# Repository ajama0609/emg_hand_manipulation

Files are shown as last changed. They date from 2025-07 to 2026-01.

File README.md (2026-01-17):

# EMG Hand Gesture Classification

## Introduction

Surface electromyography (sEMG) is a non-invasive technique for measuring muscle electrical activity and is widely used in human–machine interfaces, prosthetics, and rehabilitation systems. Reliable sEMG systems require low-noise analog front-ends, high common-mode rejection, stable power delivery, and careful PCB layout to preserve signal integrity, particularly given the low-amplitude (µV–mV) nature of EMG signals.

This project details the design, fabrication, and validation of a custom surface electromyography (sEMG) acquisition board intended to capture high-fidelity muscle signals for both real-time and offline analysis. Bypassing commercial development kits, a fully custom printed circuit board (PCB) was developed to directly address the practical engineering challenges inherent in analog signal conditioning, proper grounding techniques, filtering, and the integration of mixed-signal systems ---

# Hardware Development and Testing
A custom sEMG acquisition hardware board has been designed and fabricated to enable lightweight, low-latency, and high-fidelity signal capture for real-time applications.

Custom sEMG Acquisition Board 
 
 

### Key Components and BOM Highlights:

- **Instrumentation Amplifiers:** Texas Instruments INA333 (3 units) for high CMRR and low noise EMG signal amplification  
- **Microcontroller:** STM32F103C8T6 (ARM Cortex-M3) for signal processing and data acquisition  
- **Power Management:** Microchip MIC5504-3.3 LDO regulator for stable 3.3V supply  
- **ESD Protection:** STMicroelectronics USBLC6-2SC6 for USB interface protection  
- **Passive Components:** High-quality capacitors (e.g., TDK X5R, KEMET), resistors (Susumu, Yageo), and ferrite bead (Murata) for noise filtering and stable operation  
- **Connectors:** USB-C receptacle, 3.5mm audio jacks for signal output and power input  
- **Oscillator:** EPSON 16MHz crystal for clock generation

---

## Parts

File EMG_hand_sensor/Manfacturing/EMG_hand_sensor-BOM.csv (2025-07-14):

Designator | Quantity | Manufacturer | Manufacturer Part Number | Description | Package | Value | Type | Global Sourcing
C1 | 1 | TDK | C2012X5R1E106M125AB | 10uF Cap | 0805 | 10uF | Capacitor
C2,C3,C4,C5,C6,C16,C17,C18,C19,C20,C21 | 11 | Vishay / Vitramon | GA0805Y104KBBBT31G | 100nF Cap | 0805 | 100nF | Capacitor
C7 | 1 | KEMET | C0805X103JCRAC3316 | 10nF Cap | 0805 | 10nF | Capacitor
C8,C9,C11,C12 | 4 | KEMET | C0805X105J5RACAUTO | 1uF Cap | 0805 | 1uF | Capacitor
C13 | 1 | Vishay / Vitramon | GA0805Y104KBBBT31G | 100nF Cap | 0805 | 100n | Capacitor
C14,C15 | 2 | KEMET | C0805C100KDTACTU | 10pF Cap | 0805 | 10p | Capacitor
D1 | 1 | Kingbright | APT2012SURCK | Red LED | 0805 | RED | Diode
FB1 | 1 | Murata Electronics | BLM21AG102SN1D | Ferrite Bead | 0805 | 120R | Ferrite
J1 | 1 | GCT | USB4105-GF-A | USB-C Receptacle | USB_C_16P | USB_C | Connector | Yes
J2 | 1 | Würth Elektronik | 61300411121 | Pin Header 1x4 | 2.54mm | PinHeader | Connector | Yes
J4,J5,J6 | 3 | CUI Devices | SJ-3523-SMT-TR | 3.5mm Audio Jack | SJ-3523 | AudioJack3 | Connector | Yes
R1,R3,R4 | 3 | Susumu | RR1220P-103-D | 10k Resistor | 0805 | 10k | Resistor
R2 | 1 | YAGEO | RC0805JR-071K5L | 1.5k Resistor | 0805 | 1k5 | Resistor
R8,R9 | 2 | YAGEO | RC0402JR-074K7L | 5.1k Resistor | 0402 | 5k1 | Resistor
R11,R12,R14 | 3 | Susumu | RG2012L-332-L-T05 | 3.3k Resistor | 0805 | 3.3k | Resistor
SW1 | 1 | C&K | JS102011SAQN | SPDT Switch | SMD | SW_SPDT | Switch
U1 | 1 | STMicroelectronics | USBLC6-2SC6 | USB ESD Suppressor | SOT-23-6 | USBLC6-2SC6 | IC
U2 | 1 | STMicroelectronics | STM32F103C8T6 | STM32 MCU | LQFP-48 | STM32F103C8T6 | IC
U3,U4,U5 | 3 | Texas Instruments | INA333AIDGKR | Instrumentation Amplifier | VSSOP-8 | INA333 | IC | Yes
U6 | 1 | Microchip Technology | MIC5504-3.3YM5-TR | LDO Regulator | SOT-23-5 | 3.3V | IC
VR1,VR2,VR3 | 3 | Vishay / Sfernice | TS53YJ501MR10 | Potentiometer 500Ω | TH | 500Ω | Potentiometer | Yes
Y1 | 1 | EPSON | TSX-3225 16.0000MF10U-B0 | 16MHz Crystal | 3225 | 16MHz | Crystal

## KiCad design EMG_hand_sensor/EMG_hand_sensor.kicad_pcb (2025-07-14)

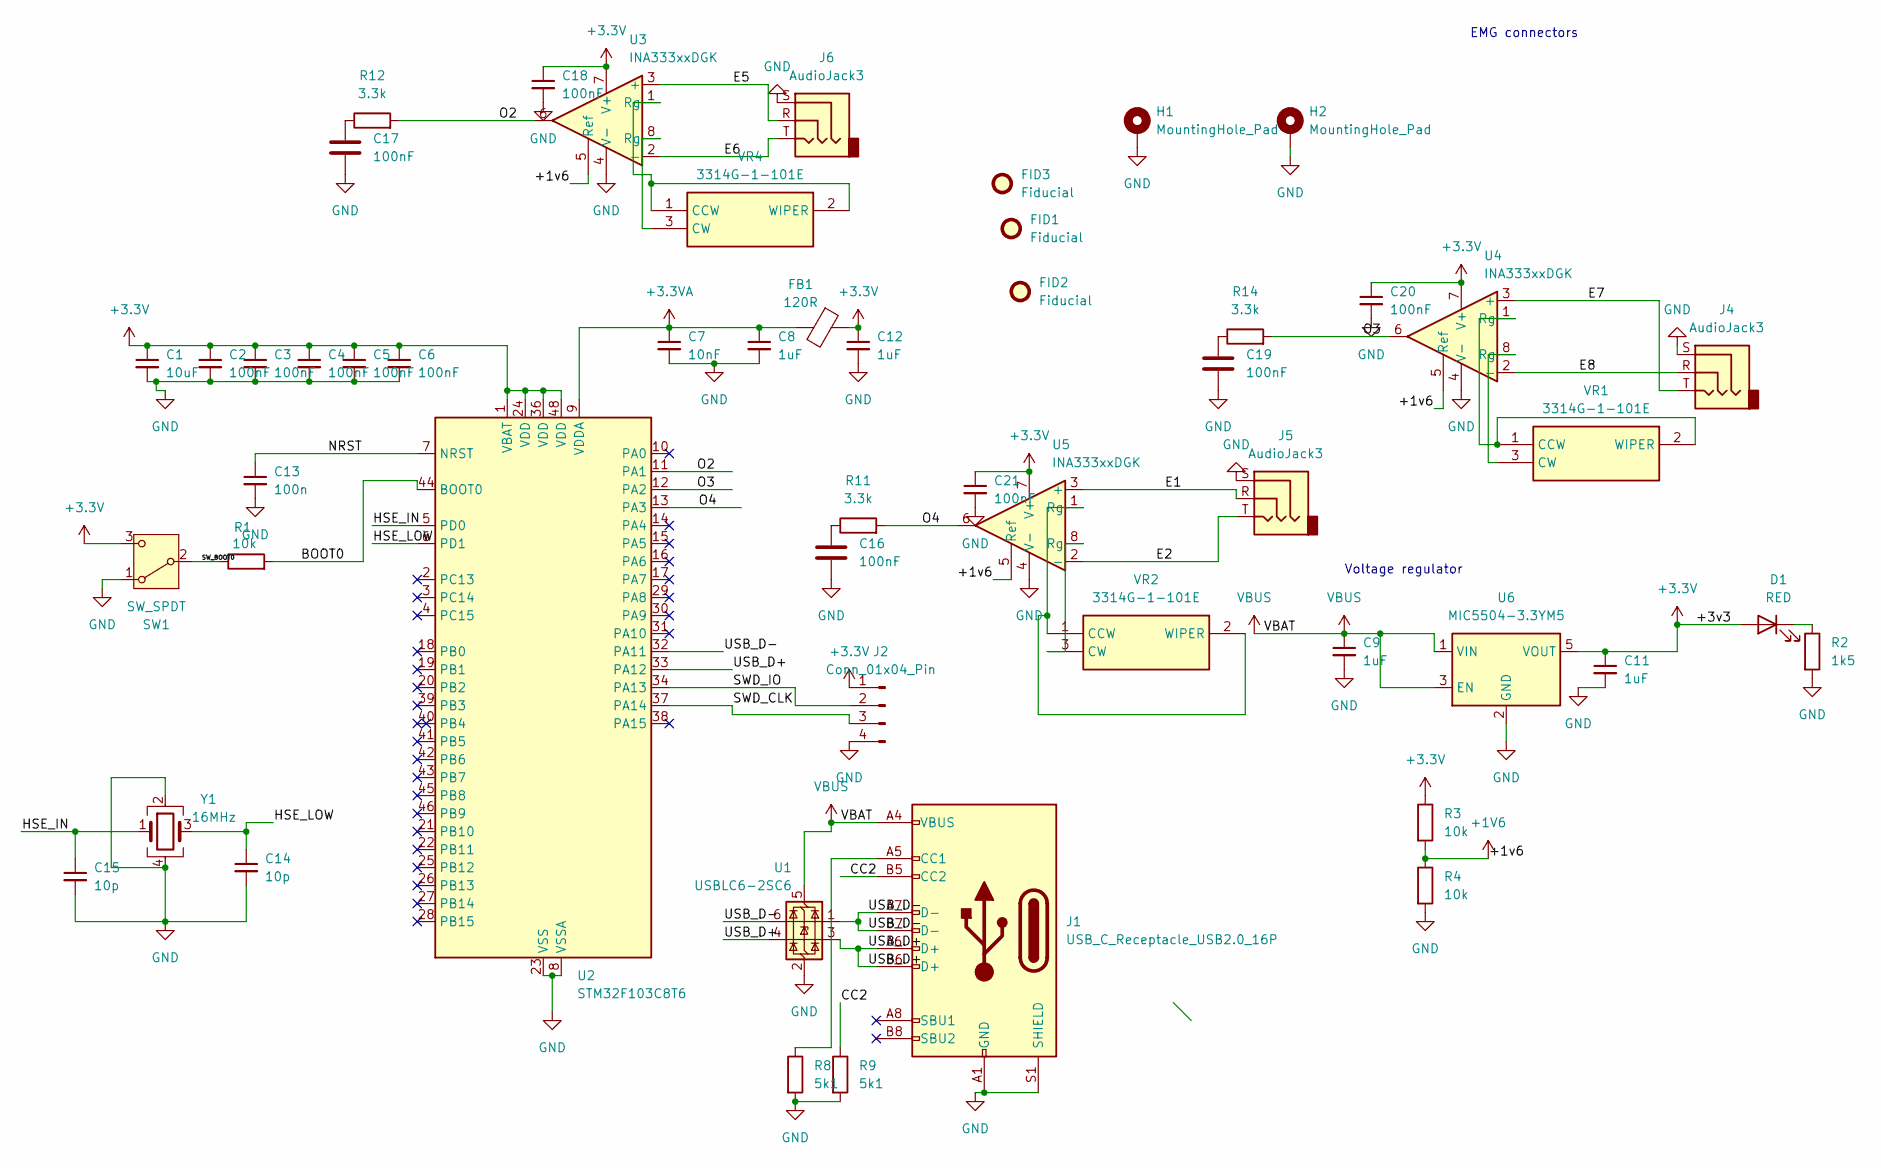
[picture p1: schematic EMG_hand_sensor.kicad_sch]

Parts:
C1: 10uF; C_0805_2012Metric_Pad1.18x1.45mm_HandSolder
C2, C3, C4, C5, C6, C16, C17, C18, C19, C20, C21: 100nF; C_0805_2012Metric_Pad1.18x1.45mm_HandSolder
C7: 10nF; C_0805_2012Metric_Pad1.18x1.45mm_HandSolder
C8, C9, C11, C12: 1uF; C_0805_2012Metric_Pad1.18x1.45mm_HandSolder
C13: 100n; C_0805_2012Metric_Pad1.18x1.45mm_HandSolder
C14, C15: 10p; C_0805_2012Metric_Pad1.18x1.45mm_HandSolder
D1: RED; D_0805_2012Metric
FB1: 120R; BLM21AG102BH1J
FID1, FID2, FID3: Fiducial; Fiducial_0.5mm_Mask2mm
H1, H2: MountingHole_Pad; MountingHole_2.2mm_M2_Pad
J1: USB_C_Receptacle_USB2.0_16P; USB_C_Receptacle_GCT_USB4105-xx-A_16P_TopMnt_Horizontal
J2: Conn_01x04_Pin; PinHeader_1x04_P2.54mm_Vertical
J4, J5, J6: AudioJack3; Jack_3.5mm_CUI_SJ-3523-SMT_Horizontal
R1, R3, R4: 10k; R_0805_2012Metric_Pad1.20x1.40mm_HandSolder
R2: 1k5; R_0805_2012Metric_Pad1.20x1.40mm_HandSolder
R8, R9: 5k1; R_0805_2012Metric_Pad1.20x1.40mm_HandSolder
R11, R12, R14: 3.3k; R_0805_2012Metric_Pad1.20x1.40mm_HandSolder
SW1: SW_SPDT; SW_SPDT_CK_JS102011SAQN
U1: USBLC6-2SC6; SOT-23-6
U2: STM32F103C8T6; LQFP-48_7x7mm_P0.5mm
U3, U4, U5: INA333xxDGK; VSSOP-8_3x3mm_P0.65mm
U6: MIC5504-3.3YM5; SOT-23-5
VR1, VR2, VR4: 3314G-1-101E; 3314G-1; Mouser Part Number 652-3314G-1-101E
Y1: 16MHz; Crystal_SMD_3225-4Pin_3.2x2.5mm

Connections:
+1V6: R3.2, R4.1, U3.5 (Ref), U4.5 (Ref), U5.5 (Ref)
+3.3V: C1.1, C2.1, C3.1, C4.1, C5.1, C6.1, C11.1, C12.1, C18.1, C20.1, C21.1, D1.2 (A), FB1.1, J2.1, R3.1, SW1.3 (C), U2.1 (VBAT), U2.24 (VDD), U2.36 (VDD), U2.48 (VDD), U3.7 (V+), U4.7 (V+), U5.7 (V+), U6.5 (VOUT)
+3.3VA: C7.1, C8.1, FB1.2, U2.9 (VDDA)
/BOOT0: R1.2, U2.44 (BOOT0)
/CC2: J1.B5 (CC2), R9.1
/E1: J5.R, U5.3 (+)
/E2: J5.T, U5.2 (-)
/E5: J6.R, U3.3 (+)
/E6: J6.T, U3.2 (-)
/E7: J4.T, U4.3 (+)
/E8: J4.R, U4.2 (-)
/HSE_IN: C15.1, U2.5 (PD0), Y1.1
/HSE_LOW: C14.1, U2.6 (PD1), Y1.3
/NRST: C13.1, U2.7 (NRST)
/O2: R12.2, U2.11 (PA1), U3.6
/O3: R14.2, U2.12 (PA2), U4.6
/O4: R11.2, U2.13 (PA3), U5.6
/SWD_CLK: J2.3, U2.37 (PA14)
/SWD_IO: J2.2, U2.34 (PA13)
/SW_BOOT0: R1.1, SW1.2 (B)
/USB_D+: J1.A6 (D+), J1.B6 (D+), U1.3 (I/O2), U1.4 (I/O2), U2.33 (PA12)
/USB_D-: J1.A7 (D-), J1.B7 (D-), U1.1 (I/O1), U1.6 (I/O1), U2.32 (PA11)
GND: C1.2, C2.2, C3.2, C4.2, C5.2, C6.2, C7.2, C8.2, C9.2, C11.2, C12.2, C13.2, C14.2, C15.2, C16.2, C17.2, C18.2, C19.2, C20.2, C21.2, H1.1, H2.1, J1.A1 (GND), J1.A12 (GND), J1.B1 (GND), J1.B12 (GND), J1.S1 (SHIELD), J2.4, J4.S, J5.S, J6.S, R2.2, R4.2, R8.2, R9.2, SW1.1 (A), U1.2 (GND), U2.8 (VSSA), U2.23 (VSS), U2.35 (VSS), U2.47 (VSS), U3.4 (V-), U4.4 (V-), U5.4 (V-), U6.2 (GND), Y1.2, Y1.4
unnamed: C16.1, R11.1
unnamed: C17.1, R12.1
unnamed: C19.1, R14.1
unnamed: D1.1 (K), R2.1
unnamed: J1.A5 (CC1), R8.1
unnamed: U4.1 (Rg), VR1.1 (CCW), VR1.2 (WIPER)
unnamed: U4.8 (Rg), VR1.3 (CW)
unnamed: U5.1 (Rg), VR2.1 (CCW), VR2.2 (WIPER)
unnamed: U5.8 (Rg), VR2.3 (CW)
unnamed: U3.1 (Rg), VR4.1 (CCW), VR4.2 (WIPER)
unnamed: U3.8 (Rg), VR4.3 (CW)
VBUS: C9.1, J1.A4 (VBUS), J1.A9 (VBUS), J1.B4 (VBUS), J1.B9 (VBUS), U1.5 (VBUS), U6.1 (VIN), U6.3 (EN)

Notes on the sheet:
Voltage regulator
EMG connectors

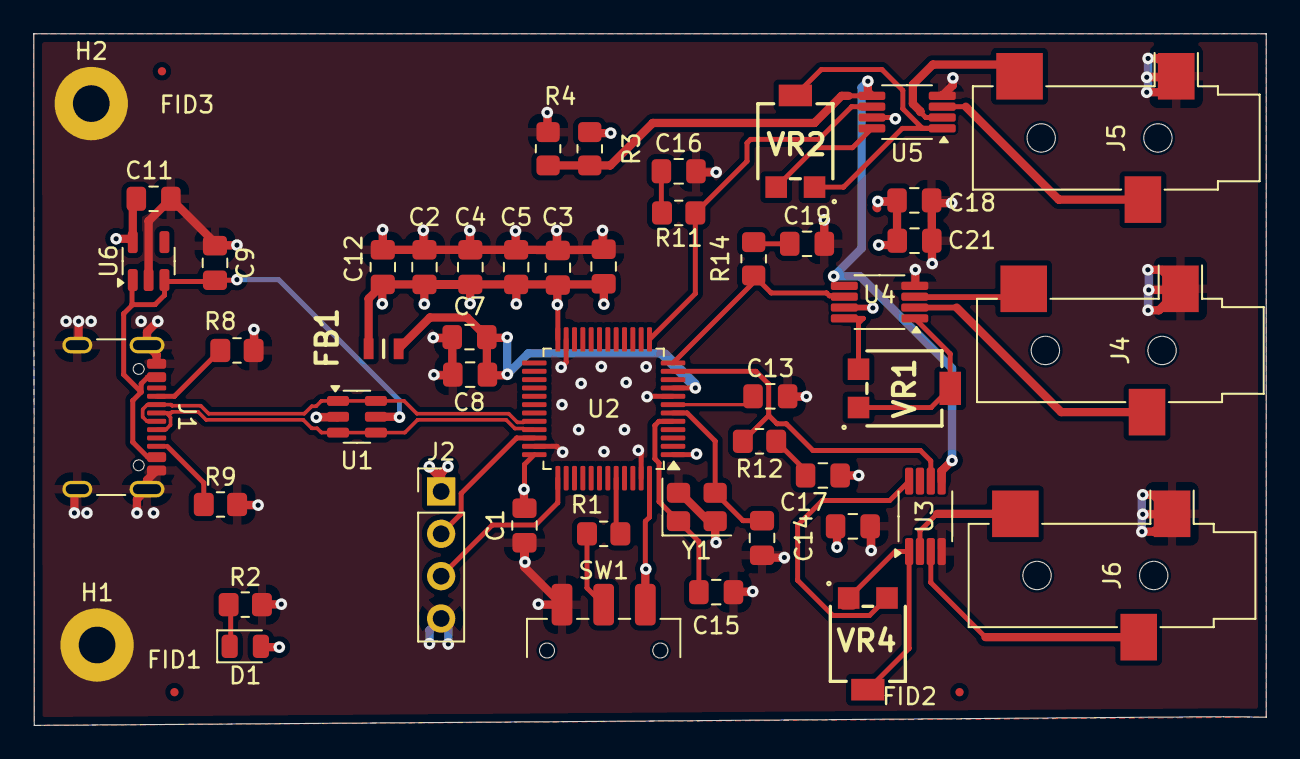
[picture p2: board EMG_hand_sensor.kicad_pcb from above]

Board: 4 copper layers, 73.9 x 41.5 mm, 52 parts (0 on the bottom side), 35 nets.

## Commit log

2025-06-25 more commits
    [emg_data_1.csv]
2025-06-25 emg filtering
2025-06-26 filtered fft of first window
2025-06-30 LTspice circuit for analogue frontend
2025-07-02 Extracted features as csv file next step parse it in python normalize it and use it as a input to my pytorch model
    [features.csv]
2025-07-02 updated features
    [features.csv]
2025-07-03 updated files
    [features.csv]
2025-07-04 Trying with 8 channels now
    [features.csv]
2025-07-04 new features
    [new_features.csv]
2025-07-04 stm32 files
2025-07-05 trying to not filter out the rest hand state
    [new_features.csv]
2025-07-05 tidying up codebase
    [emg_data_1.csv, features.csv]
2025-07-07 building some more
    [EMG_hand_sensor.kicad_pcb, EMG_hand_sensor.kicad_sch, features1.csv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]
2025-07-07 Update:got both the hpf and lpf filter reponses
2025-07-09 finished schematics and test
    [EMG_hand_sensor.kicad_sch]
2025-07-10 finished with first schematic for now
    [EMG_hand_sensor.kicad_sch]
2025-07-10 starting pcb design
    [EMG_hand_sensor.kicad_sch]
2025-07-10 component placement and design rules
    [EMG_hand_sensor.kicad_pcb, EMG_hand_sensor.kicad_sch]
2025-07-10 completley chnaged from analog to digital
    [EMG_hand_sensor.kicad_sch]
2025-07-10 running ERC
    [EMG_hand_sensor.kicad_sch]
2025-07-10 new schematic done
    [EMG_hand_sensor.kicad_pcb, EMG_hand_sensor.kicad_sch]
2025-07-10 pcb design started layout
    [EMG_hand_sensor.kicad_pcb]
2025-07-10 starting pch layout
    [EMG_hand_sensor.kicad_pcb, EMG_hand_sensor.kicad_sch]
2025-07-11 design rules
    [EMG_hand_sensor.kicad_pcb]
2025-07-11 pcb layout finished
    [EMG_hand_sensor.kicad_pcb, EMG_hand_sensor.kicad_sch]
2025-07-11 routing time
    [EMG_hand_sensor.kicad_pcb, EMG_hand_sensor.kicad_sch]
2025-07-11 Need to add guard traces and vias and then I can start routing
    [EMG_hand_sensor.kicad_pcb, EMG_hand_sensor.kicad_sch]
2025-07-12 done with most of the routing
    [EMG_hand_sensor.kicad_pcb, EMG_hand_sensor.kicad_sch]
2025-07-12 Finalising board running DRC
    [EMG_hand_sensor.kicad_pcb]
2025-07-12 done DRC final checks
    [EMG_hand_sensor.kicad_pcb]
2025-07-12 ready for ordering
    [EMG_hand_sensor.kicad_pcb]
2025-07-12 gerber files and BOM
    [EMG_hand_sensor-B_Cu.gbr, EMG_hand_sensor-B_Mask.gbr, EMG_hand_sensor-Edge_Cuts.gbr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]
2025-07-12 order pending
    [EMG_hand_sensor-BOM.csv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]
2025-07-12 need to change some things because jlcpcb stock
    [EMG_hand_sensor-BOM.csv, EMG_hand_sensor.kicad_pcb, EMG_hand_sensor.kicad_sch]
2025-07-12 some changes
    [EMG_hand_sensor-BOM.csv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]
2025-07-12 looks good
    [EMG_hand_sensor.kicad_pcb, EMG_hand_sensor.kicad_sch]
2025-07-13 done ordered
    [EMG_hand_sensor-BOM.csv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]
2025-07-13 some changes to imporve noise
    [EMG_hand_sensor-B_Cu.gbr, EMG_hand_sensor-B_Mask.gbr, EMG_hand_sensor-Edge_Cuts.gbr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]
2025-07-14 updated for cheaper parts
    [EMG_hand_sensor.kicad_pcb, EMG_hand_sensor.kicad_sch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]
2025-07-14 ordered boards from jlcpcb
    [EMG_hand_sensor-BOM.csv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]
2025-07-16 snn features
    [features1.csv]
2025-07-16 snn featues 34 columsn
    [featuressnn.csv]
2025-07-17 trying to incorporate snn
    [features1.csv]
2025-07-19 DB1 labelled feature extracted RMS
    [s1_feat.csv]
2025-07-19 added frequency feats as well as time domain
    [s1_feat.csv]
2025-07-19 updated model script
    [pyvenv.cfg]
2025-07-24 stacking feats
    [total_feats.csv]
